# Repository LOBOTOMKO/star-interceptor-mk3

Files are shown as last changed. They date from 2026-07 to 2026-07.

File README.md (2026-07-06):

# Star Interceptor MK III

**An autonomous celestial-tracking telescope mount — designed and built end to end: mechanism, technical drawings, custom PCB, firmware, and control app.**

A low-cost, portable two-axis mount that works out where a celestial object sits in the sky from your time and location, then drives itself to follow it across the sky — on its own, for up to 24 hours.

*Regional winner and national finalist, Festival of Science & Technology (AMAVET).*

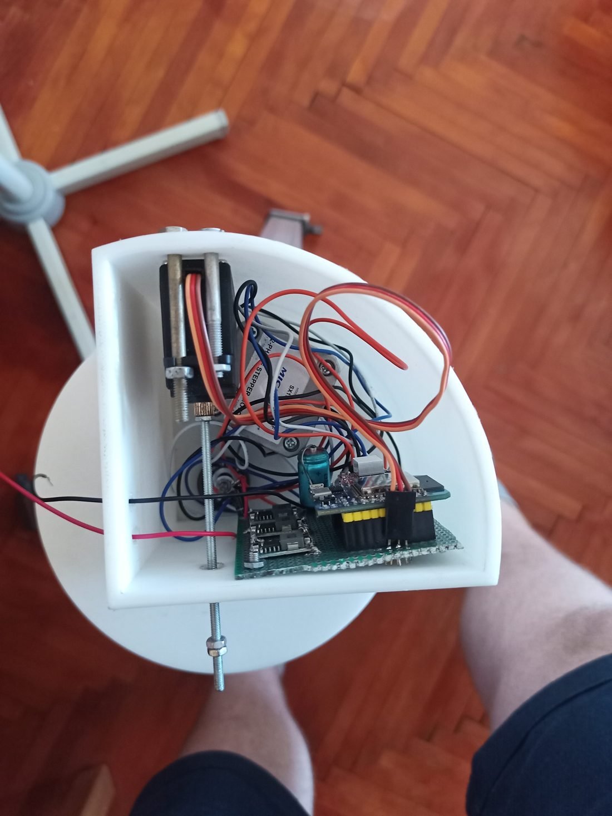
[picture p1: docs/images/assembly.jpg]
The assembled instrument — steppers, custom board and wiring inside the 3D-printed base


---

## Overview

I built this because the cheap telescope I had as a kid sat on a tripod too flimsy to hold the full Moon steady in view — and the computer-controlled mount I'd been promised never got built. So I spent about a year researching the technologies it would need and built it myself.

The goal was a genuinely affordable, durable, portable platform that points a telescope precisely from a smartphone — and, just as much, a project to push my own engineering across every layer: mechanical design, electronics, firmware, and software.

The result is a working instrument that ran in front of a competition jury twice, in two countries.

---

## How it works

The system answers one question, continuously: **where is this object right now?** From the observer's coordinates, elevation and the current time, it computes the target's apparent position, converts that into a pair of axis angles — azimuth and altitude — and drives the mount to match, recomputing as the sky moves.

```
observer location + time + target  →  celestial-position computation  →  azimuth / altitude  →  two-axis motion
```

---

## The build — three generations, each solving the last one's failure

The mount wasn't designed once and finished. It evolved through **diagnosed failures** — each version fixed a specific, observed problem in the one before. That loop of build → test → find the real fault → redesign is the core of the project.

**Generation 1 — dual stepper, H-bridge drive.**
Both axes driven by stepper motors through H-bridges. Original firmware preserved in [`firmware/history/gen1-dual-stepper/`](firmware/history/gen1-dual-stepper/).
*The failure:* with the drivers powered down, the telescope's own weight back-drove the motors and it slipped off target — along with vibration, jitter and audible noise.

**Generation 2 — servo elevation (MG996R).**
Moving elevation to a metal-geared servo with position feedback fixed the back-driving.
*The new failure:* the servo's acceleration couldn't be controlled, so under the inertia of the optics it fell into a chaotic state and couldn't reliably settle on the commanded angle.

**Generation 3 — stepper + worm gear (in development).**
The current direction: a worm-gear-driven stepper for elevation. A worm drive can't be back-driven, raises load capacity, and removes the jerk on pointing changes. This is the MK III.

---

## Software

Celestial positions are computed in **Python**, using the `ephem` library — chosen because it handles far more bodies than the alternatives. The control app is built in **Kotlin** with an XML interface in **Android Studio** (both taught myself for this project), bridged to the Python calculation through **Chaquopy**. The mount runs a **Bluetooth Low Energy** server on the **ESP32**.

The step I'm most proud of is how tracking is handled. In the first version the phone recomputed the target every 10 seconds and pushed the mount a correction. In the second, the phone hands the mount a compact array of upcoming orientations, and the mount then tracks the object **entirely on its own — no phone connection needed — for up to 24 hours.**

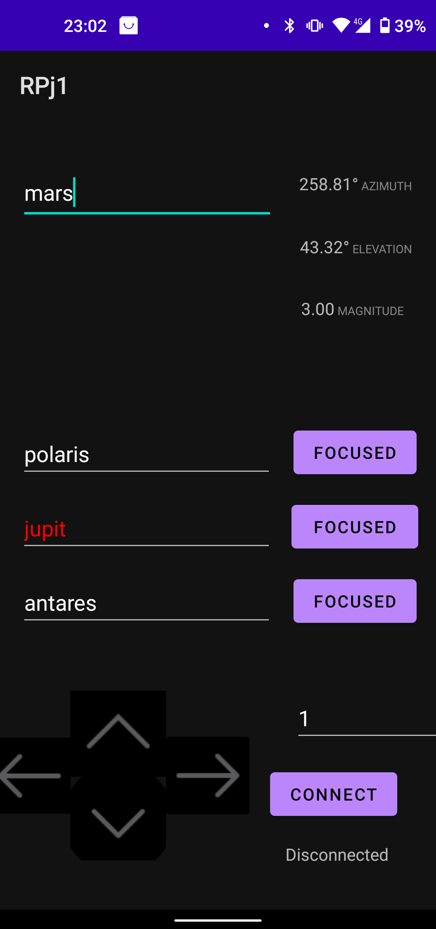
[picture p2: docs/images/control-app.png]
The control app — target entry with live azimuth, elevation and magnitude readout, plus manual controls


---

## Engineering detail: S-curve acceleration

Driven naively, stepper motors start and stop abruptly — which shows up as vibration, noise, and missed steps that cost pointing accuracy. To fix it I derived a **sigmoid-based S-curve acceleration profile**: rather than jumping between step speeds, the firmware ramps the delay between steps smoothly up to speed and back down again, so each axis accelerates and brakes gently. The result is quiet, controlled motion that doesn't shake the optics or lose position.

```cpp
double computeY(double x, double k, double d, double v) {
    double t1 = 1.0 / (1.0 + exp(-k * (x - (2*log(v)/k) + d)));
    double t2 = 1.0 / (1.0 + exp(-k * (x + (2*log(v)/k) - d)));
    return 0 - fabs(t1 - t2) * v;   // per-step delay along the acceleration curve
}
```

---

## Electronics & power

The electronics began as stepper drivers wired by hand and became a consolidated unit. I moved from **A4988 to DRV8825** drivers for finer microstepping, lower noise and a cleaner control interface, then brought the ESP32, the drivers and a Mini-360 buck converter together onto a **custom PCB designed in KiCad** — a plug-and-play board rather than a breadboard of modules. An SMD revision of the board is already designed.

Power comes from an **18650 pack** I reconfigured from a series/parallel layout into full series, to supply the 8 V+ the DRV8825 drivers need to run.

**Schematic (KiCad)**
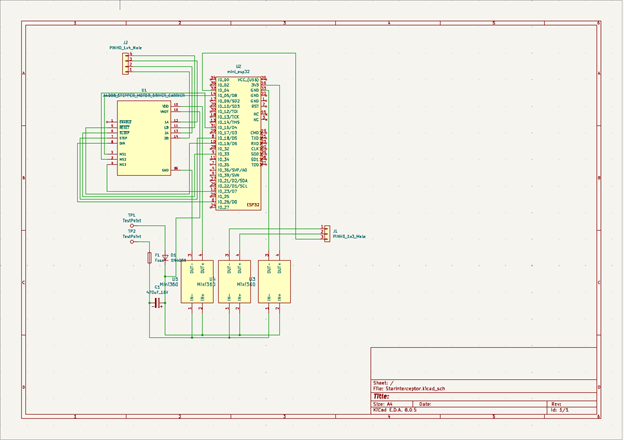
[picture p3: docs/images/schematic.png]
Custom PCB schematic — ESP32, stepper driver, buck converters and protection on one board


**Board layout (KiCad)**
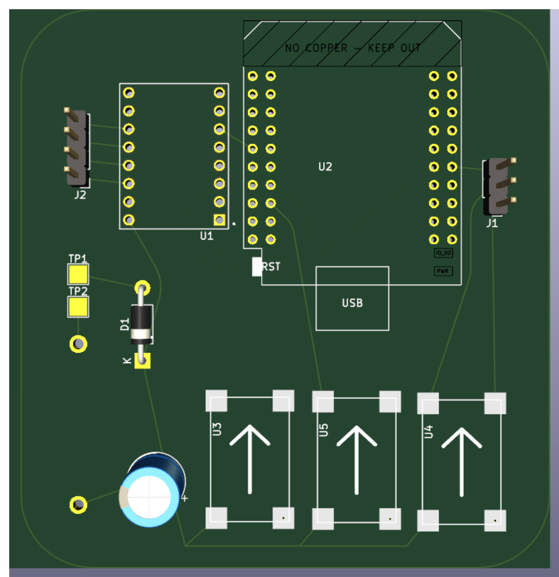
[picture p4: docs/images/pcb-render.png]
PCB layout render


**Power**
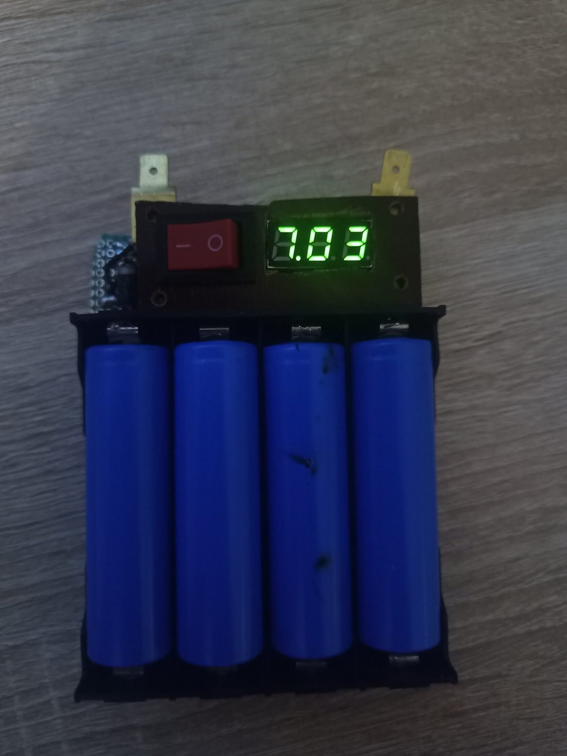
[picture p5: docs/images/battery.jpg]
The 18650 battery pack, reconfigured to full series for driver headroom


> Note: the original KiCad source files were lost; the schematic and board images above are the surviving record of the electronics design.

---

## CAD & technical documentation

The full mechanism was modelled in **Autodesk Fusion 360** and exported through PrusaSlicer for 3D printing. Beyond the models, every part is captured as a **dimensioned technical drawing** — dome and base included — with tolerances, radii, section views and title blocks. This is production documentation, not just a 3D file: drawings another person could manufacture from directly.

| Dome (Kupola) | Base (Základňa) |
|:---:|:---:|
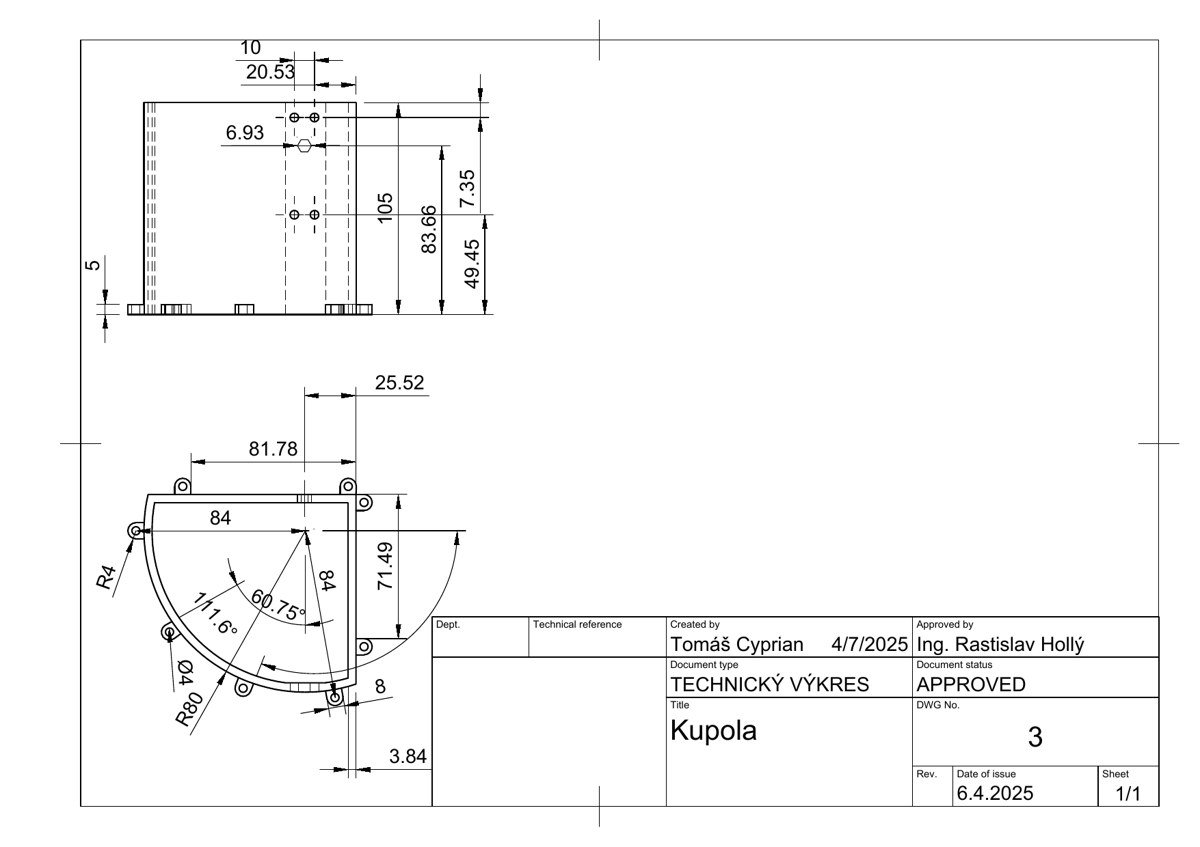
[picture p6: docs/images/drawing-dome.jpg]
Technical drawing of the dome, fully dimensioned
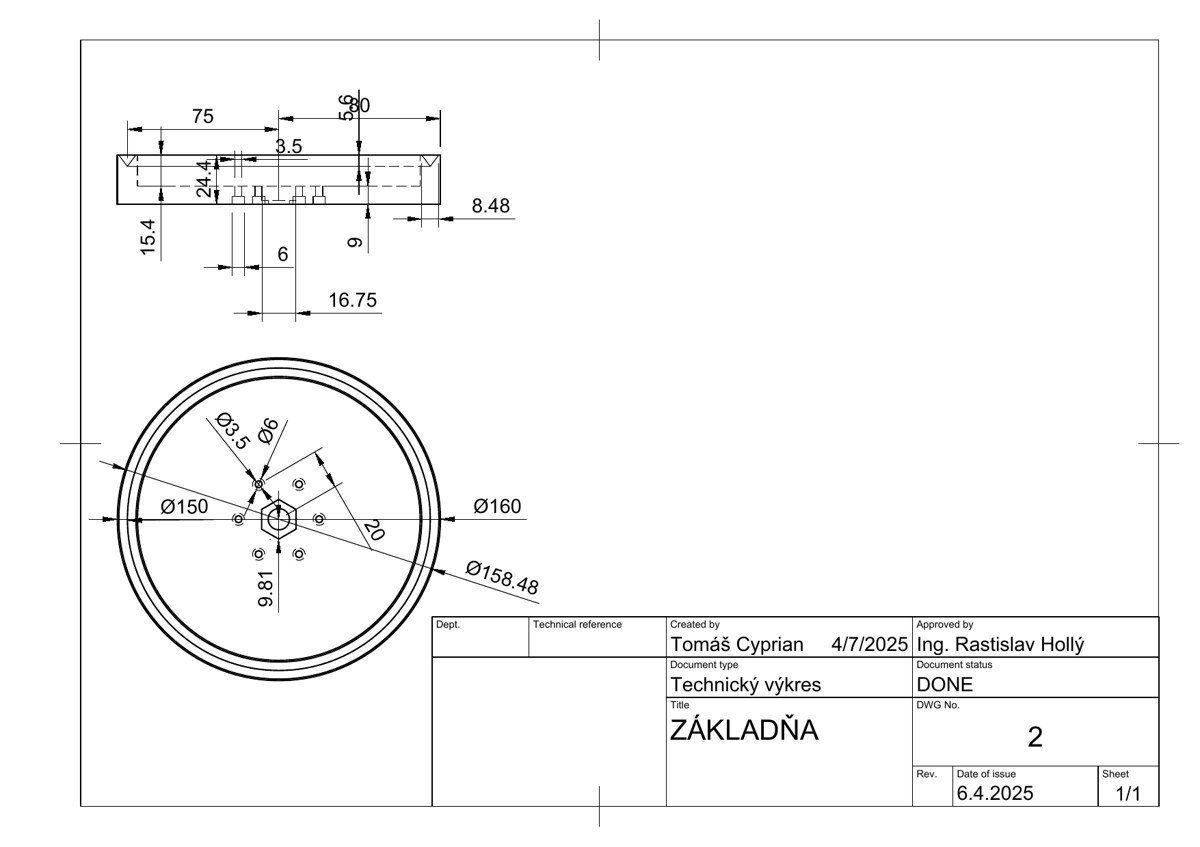
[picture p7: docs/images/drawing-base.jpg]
Technical drawing of the base with title block
|  |  |

**3D models** — click through for GitHub's interactive rotate/zoom viewer:
[Základňa (base)](cad/stl/Zakladna-v2.stl) · [Točňa (turntable)](cad/stl/Tocna-v2.stl) · [Námer 1](cad/stl/Namer1-v2.stl) · [Námer 2](cad/stl/Namer2-v2.stl)

> More early-stage STL variants and other archived files live in the earlier [Star-Interceptor](https://github.com/LOBOTOMKO/Star-Interceptor) repository (`3D/`).

---

## Cost

The affordability goal wasn't a slogan — the complete bill of materials came to **€31.85**. Designing to a real cost target, and hitting it, was part of the engineering brief I set myself.

| Component | Cost |
|---|---|
| ESP32 (Wemos D1 mini) | €9.90 |
| Stepper motor (17HS4023) | ~€2.50 |
| DRV8825 driver | €2.95 |
| Servo (MG996R) | €6.90 |
| 2× Mini-360 buck converter | €0.95 |
| Battery | €7.70 |
| **Total** | **€31.85** |

---

## Recognition

- **Festival of Science & Technology (AMAVET), 2023** — regional winner (Trenčín region), presented in the national final at INCHEBA Bratislava. Category: Physics & Astronomy.
- **Festival of Science & Technology, 2025** — regional round, Pardubice (Czech Republic). Partners included Foxconn and the University of Pardubice.

---

## Repository structure

```
star-interceptor/
├── firmware/     ESP32 firmware (C/C++) — coordinate transform, motor control, BLE server
├── app/          Android control app (Kotlin / XML)
├── calc/         Python celestial-position calculation (ephem)
├── hardware/     KiCad schematic + PCB layout (images)
├── cad/          Fusion 360 exports + dimensioned technical drawings (PDF)
└── docs/images/  Photos, schematic, board render, drawings, app screenshot
```

---

## About

Designed and built by **Tomáš Cyprian** — Applied Informatics (Robotics & Control Systems).
Open to engineering and design work.

📧 tomas.cyprian.sk@gmail.com

*The project is open for hobbyists and enthusiasts to build on.*

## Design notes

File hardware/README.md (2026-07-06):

# hardware/

Electronics design — custom PCB carrying the ESP32, stepper driver, buck converters and protection.

Designed in KiCad. **Note:** the original KiCad source files were lost; the schematic and board-layout images in `docs/images/` (`schematic.png`, `pcb-render.png`) are the surviving record. If the `.kicad_pro` / `.kicad_sch` / `.kicad_pcb` files are recovered, add them here.

**Add here:** any recovered KiCad project files and exported gerbers.

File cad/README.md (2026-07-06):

# cad/

Mechanical design — modelled in Autodesk Fusion 360, printed via PrusaSlicer.

Includes dimensioned technical drawings (dome and base) with tolerances, section views and title blocks.

**STL meshes:** `stl/` holds the current printable meshes — open one on GitHub to get its interactive rotate/zoom viewer. More early-stage variants and other archived files live in the earlier [Star-Interceptor](https://github.com/LOBOTOMKO/Star-Interceptor) repository (`3D/`).

**Add here:** Fusion exports (`.f3d` / `.step`) and the technical-drawing PDFs.

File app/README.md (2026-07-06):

# app/

Android control application (Kotlin, XML UI, built in Android Studio).

- target selection and manual control
- computes celestial positions via the bundled Python (`calc/`) through Chaquopy
- sends orientations to the mount over Bluetooth Low Energy

**Add here:** the Android Studio project (module sources, `build.gradle`, resources). Build artifacts are ignored by `.gitignore`.

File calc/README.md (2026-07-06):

# calc/

Celestial-position calculation (Python, `ephem`).

Given an observer's latitude, longitude, elevation and the current time, computes a target body's azimuth, altitude and magnitude — and produces the sequence of upcoming orientations used for autonomous tracking.

**Add here:** the Python source and a `requirements.txt` (e.g. `ephem`).

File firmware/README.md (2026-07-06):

# firmware/

ESP32 firmware (C/C++).

Handles the real-time work on the mount:
- receives target orientations over Bluetooth Low Energy
- runs the coordinate → axis-angle logic
- drives the stepper motor(s) with the S-curve acceleration profile
- (v2) tracks an object autonomously from a buffered orientation array

**Add here:** the ESP32 source (`.ino` / `.cpp` / `.h`) and any PlatformIO/Arduino project files.

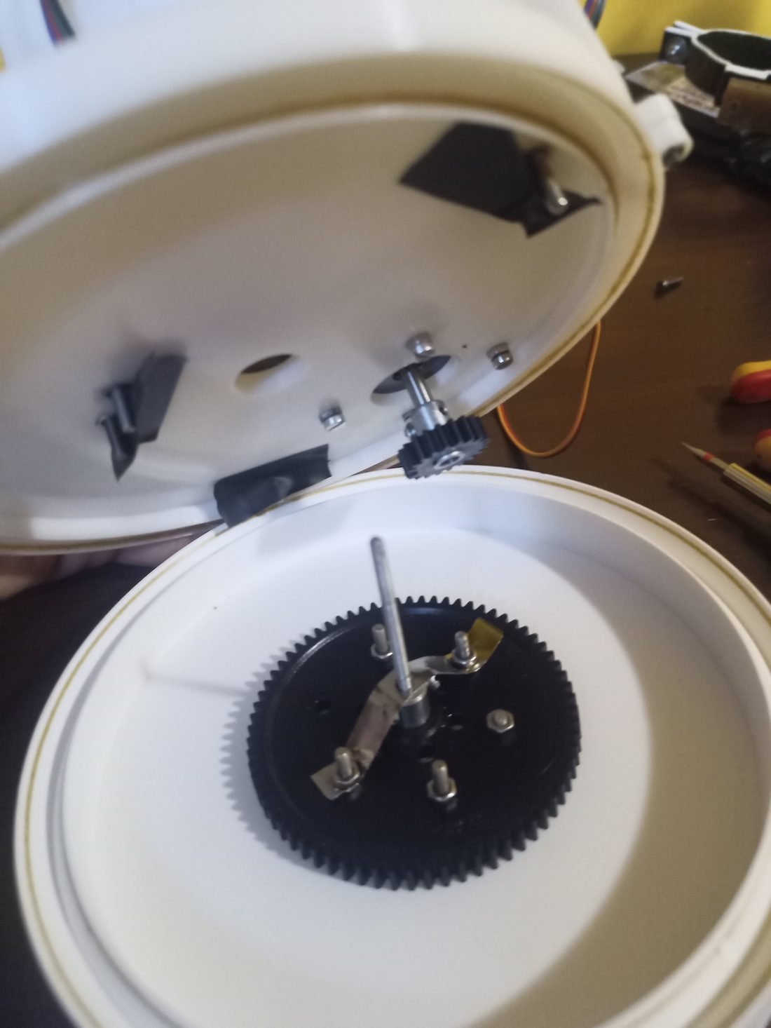
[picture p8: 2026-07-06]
docs/images/drivetrain.jpg

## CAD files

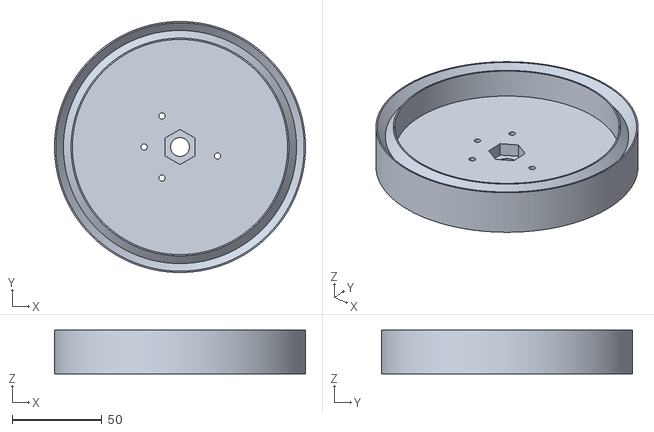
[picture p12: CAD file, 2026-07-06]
cad/stl/Zakladna-v2.stl
140.0 x 140.0 x 24.4

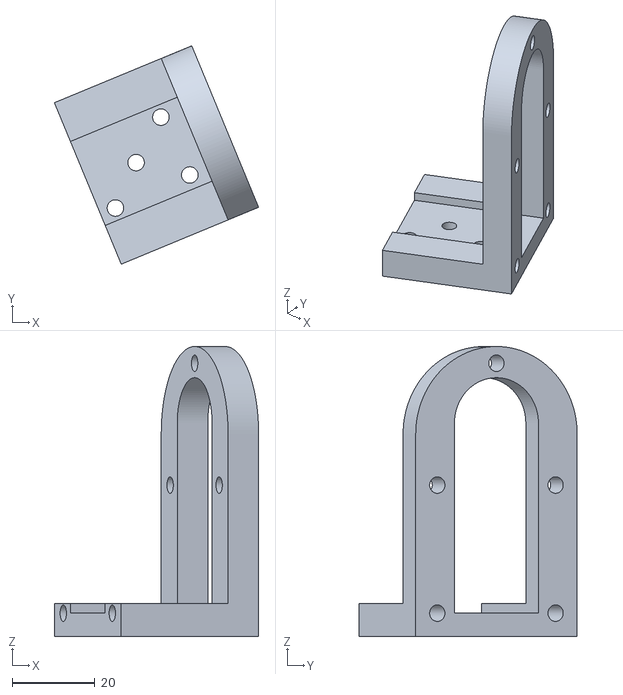
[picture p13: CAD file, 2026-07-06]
cad/stl/Namer1-v2.stl
49.4 x 52.9 x 70.2

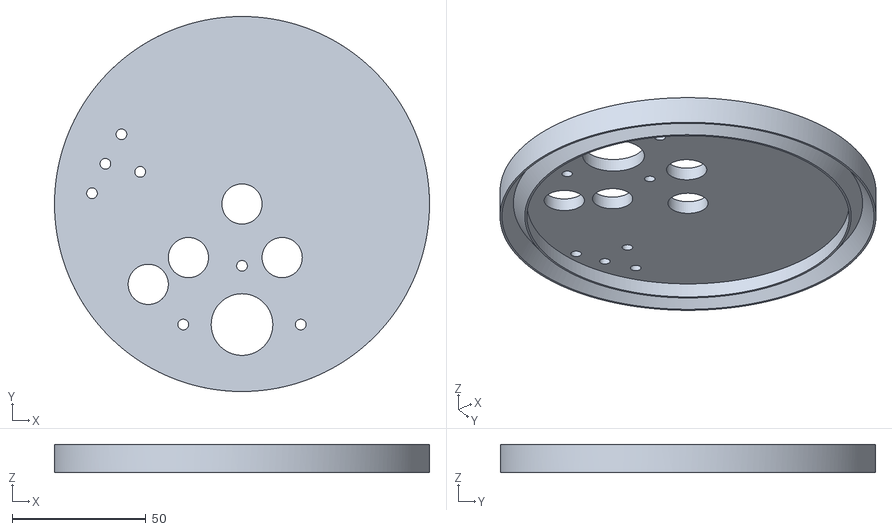
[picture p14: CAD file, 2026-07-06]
cad/stl/Tocna-v2.stl
140.0 x 140.0 x 10.6

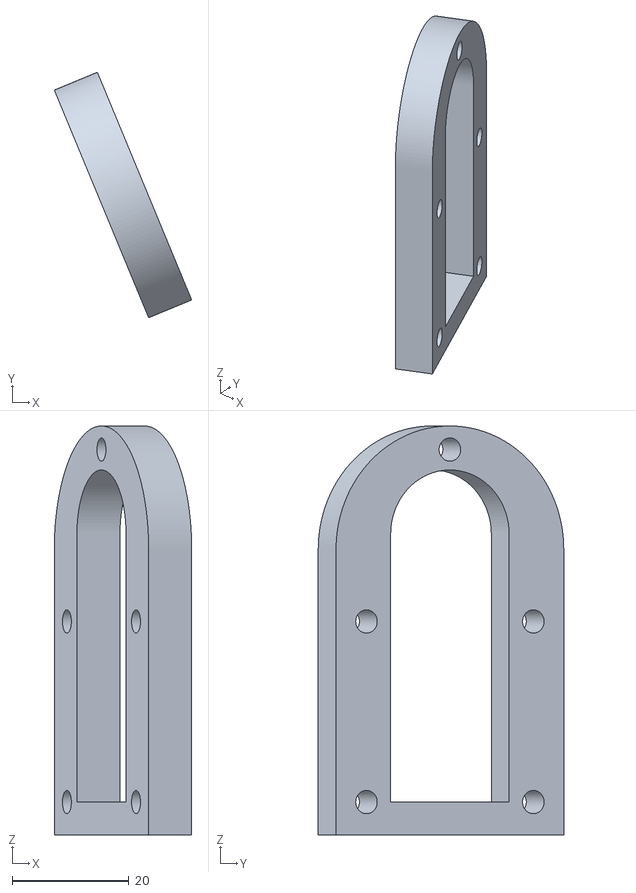
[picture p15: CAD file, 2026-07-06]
cad/stl/Namer2-v2.stl
23.6 x 42.1 x 70.2

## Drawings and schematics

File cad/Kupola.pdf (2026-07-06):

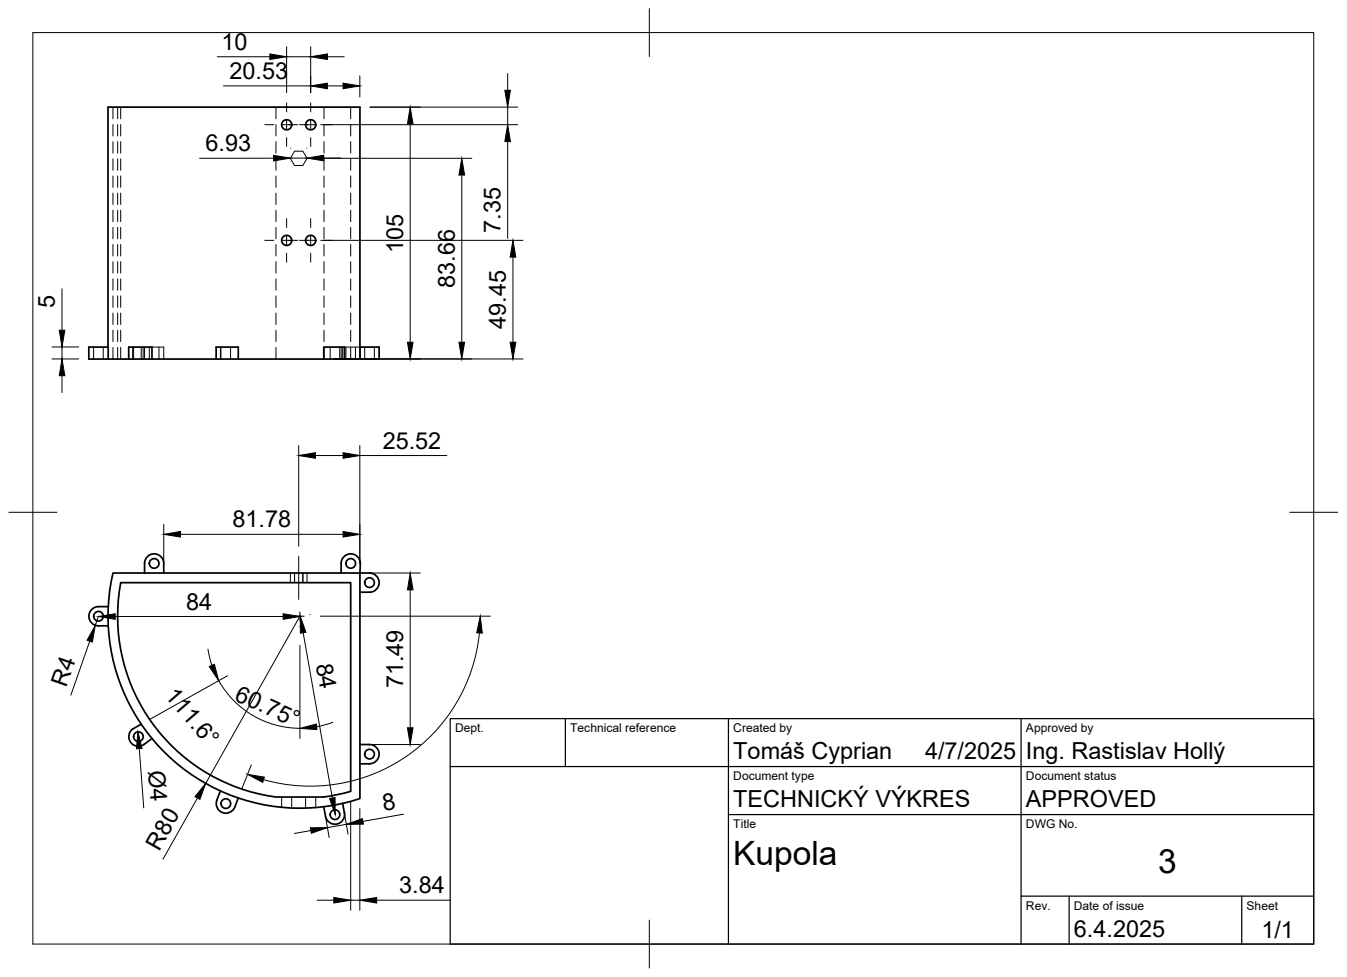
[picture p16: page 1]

Dept. | Technical reference | Created by Tomáš Cyprian 4/7/2025 | Approved by Ing. Rastislav Hollý

Document type TECHNICKÝ VÝKRES | Document status APPROVED

Title Kupola | DWG No. 3

Rev. | Date of issue 6.4.2025 | Sheet 1/1

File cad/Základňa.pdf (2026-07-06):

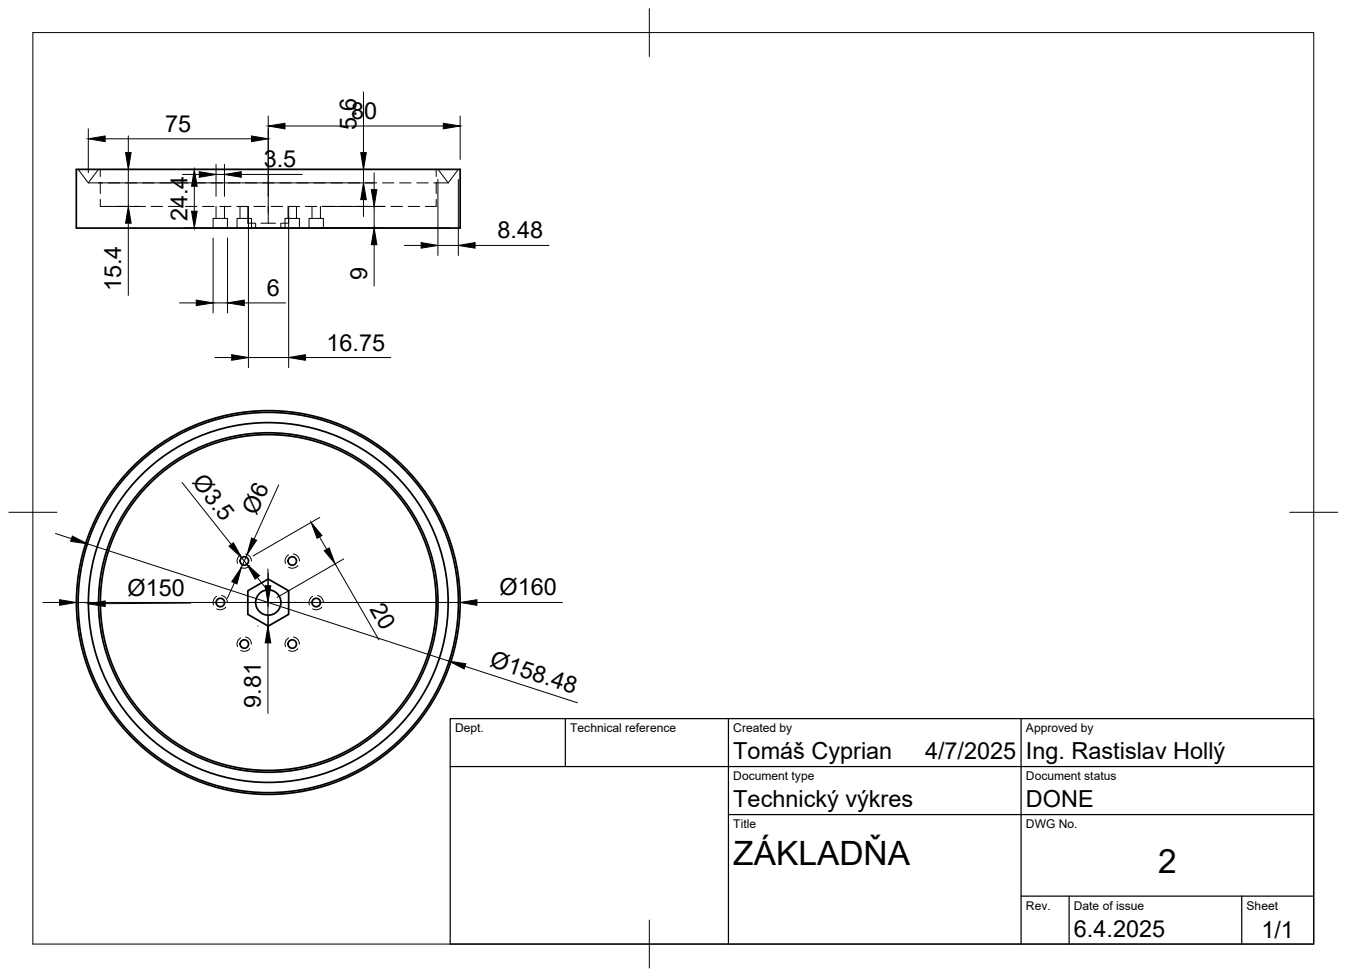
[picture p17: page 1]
Tomáš Cyprian; Ing. Rastislav Hollý 24.4

Dept. | Technical reference | Created by 4/7/2025 | Approved by

Document type Technický výkres | Document status DONE

Title ZÁKLADŇA | DWG No. 2

Rev. | Date of issue 6.4.2025 | Sheet 1/1

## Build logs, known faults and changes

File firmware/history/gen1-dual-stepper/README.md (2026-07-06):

# firmware/history/gen1-dual-stepper/

The original Generation 1 firmware, kept here as a record of the project's evolution (see the main [README](../../../README.md#the-build--three-generations-each-solving-the-last-ones-failure)).

In this generation **both axes — azimuth and elevation — were driven by stepper motors**, each stepped directly through a 4-pin H-bridge sequence (no microstepping driver yet). Target coordinates arrived over Bluetooth Low Energy (`main.ino`) and were converted into step counts for MOTOR1 (azimuth) and MOTOR2 (elevation).

- `main.ino` — the BLE-driven dual-stepper controller: receives a `latitude longitude` pair, converts it into step counts, and drives both H-bridge steppers.
- `rxtx1.ino` — an earlier bring-up sketch exercising the elevation and azimuth H-bridge pin sequences directly, before the BLE layer was added.

**Why it was replaced:** with the H-bridge drivers powered down between moves, the telescope's own weight back-drove the elevation motor and it slipped off target, along with vibration, jitter and audible noise during stepping. Generation 2 moved elevation to a metal-geared servo (MG996R) with position feedback to fix the back-driving; Generation 3 (the current firmware in `firmware/`) returns elevation to a stepper, but now through a worm gear, which can't be back-driven.

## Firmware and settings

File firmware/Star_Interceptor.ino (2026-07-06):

/*
███████╗████████╗ █████╗ ██████╗     ██╗███╗   ██╗████████╗███████╗██████╗  ██████╗███████╗██████╗ ████████╗ ██████╗ ██████╗ 
██╔════╝╚══██╔══╝██╔══██╗██╔══██╗    ██║████╗  ██║╚══██╔══╝██╔════╝██╔══██╗██╔════╝██╔════╝██╔══██╗╚══██╔══╝██╔═══██╗██╔══██╗
███████╗   ██║   ███████║██████╔╝    ██║██╔██╗ ██║   ██║   █████╗  ██████╔╝██║     █████╗  ██████╔╝   ██║   ██║   ██║██████╔╝
╚════██║   ██║   ██╔══██║██╔══██╗    ██║██║╚██╗██║   ██║   ██╔══╝  ██╔══██╗██║     ██╔══╝  ██╔═══╝    ██║   ██║   ██║██╔══██╗
███████║   ██║   ██║  ██║██║  ██║    ██║██║ ╚████║   ██║   ███████╗██║  ██║╚██████╗███████╗██║        ██║   ╚██████╔╝██║  ██║
╚══════╝   ╚═╝   ╚═╝  ╚═╝╚═╝  ╚═╝    ╚═╝╚═╝  ╚═══╝   ╚═╝   ╚══════╝╚═╝  ╚═╝ ╚═════╝╚══════╝╚═╝        ╚═╝    ╚═════╝ ╚═╝  ╚═╝                                                                                                                           
*/





//MS1 repin
#include <BLEDevice.h>
#define SERVICE_UUID        "6e400001-b5a3-f393-e0a9-e50e24dcca9e"
#define CHARACTERISTIC_UUID "6e400003-b5a3-f393-e0a9-e50e24dcca9e"

#include <thread>
#include <future>
#include <atomic>
#include <ESP32Servo.h>
#define SERVO_PIN 4
Servo servoMotor;

#include <FastAccelStepper.h>
FastAccelStepperEngine engine = FastAccelStepperEngine();
FastAccelStepper *stepper = NULL;



int led = 2;

// = 0,5n
float stepAngle = 0.016071428571875;//0.5142857143;
int   speed     =     1;

float azimuth   = 0.0;
float elevation = 90.0;

//Stepper
int dir       = 26;
int step      = 18;
int sleepPin  = 33;
int reset     = 19;
int enablePin = 22;

int MS1       = 14;
int MS2       = 16;
int MS3       = 23;

static int n = 2; 
static float* floatArray;  

float azimuthal = 30.0;
float elevational  = 31.0;

float planet = 34.0;


/*
  _____                    __  .__                      
_/ ____\_ __  ____   _____/  |_|__| ____   ____   ______
\   __\  |  \/    \_/ ___\   __\  |/  _ \ /    \ /  ___/
 |  | |  |  /   |  \  \___|  | |  (  <_> )   |  \\___ \ 
 |__| |____/|___|  /\___  >__| |__|\____/|___|  /____  >
                 \/     \/                    \/     \/
*/
std::atomic<bool> keepRunning(true);

float calculateClosestApproach(float start_angle, float target_angle, float step_size) {
    float raw_diff = target_angle - start_angle;
    
    if (raw_diff > 180.0) {
        raw_diff -= 360.0;
    } else if (raw_diff < -180.0) {
        raw_diff += 360.0;
    }
    
    float nearest_step = round(raw_diff / step_size) * step_size;
    
    return nearest_step;
}

float* stringToFloatArray(const std::string& value) {
    if (value.empty()) {
        return nullptr;
    }

    const uint8_t* data = reinterpret_cast<const uint8_t*>(value.c_str());
    size_t dataSize = value.length();
    
    size_t numFloats = dataSize / sizeof(float);
    
    if (numFloats == 0) {
        return nullptr;
    }


    float* floatArray = new float[numFloats];
    memcpy(floatArray, data, numFloats * sizeof(float));
  
    for(size_t i = 0; i < numFloats; i++) {
        Serial.println(floatArray[i]);
    }
    
    return floatArray;
}

void turn(float angle, bool elevate){

  Serial.println("Turn Signal ====================================================");
  //Serial.println("angle: " + String(angle,4));
  //Serial.println("elevate: " + String(elevate,4));
  if (elevate)
  {
    if (angle > 90 && angle < 150){
      servoMotor.write(angle);
      elevation = angle;
      Serial.println("Elevation: " + String(elevation, 3));
    }
  } 
  else
  { 
    float clossestAngle = calculateClosestApproach(azimuth, angle, stepAngle);
    int steps = int(clossestAngle/stepAngle);
    azimuth = azimuth + clossestAngle;
    Serial.println("steps: " + String(steps) + "| angle: " + String(azimuth, 6) + "Azimuth");

    //digitalWrite(enablePin, LOW);
    stepper->move(steps);
    while(stepper->isRunning()) {
      yield();
    }

    //digitalWrite(enablePin, HIGH);

    digitalWrite(dir, LOW);
    digitalWrite(led, LOW);
  }
}

void trackObject(float* Angles, int speed) {
    auto nextTimePoint = std::chrono::steady_clock::now();
    int index = 1;
    while (keepRunning) {
        nextTimePoint += std::chrono::seconds(speed); 
        //subFunction(Angles[index], Angles[index+1]);
        Serial.println("Azimuth" + String(Angles[index + 1]));
        turn(Angles[index + 1], false);  // Elevation
        Serial.println("Elevation" + String(Angles[index]));
        turn(Angles[index], true);  
        
        index += 2;
        std::future<void> result = std::async(std::launch::async, [nextTimePoint]() {
            std::this_thread::sleep_until(nextTimePoint); 
        });
        result.get(); 
    }
}

/*
 _______   ___       _______  
|   _  "\ |"  |     /"     "| 
(. |_)  :)||  |    (: ______) 
|:     \/ |:  |     \/    |   
(|  _  \\  \  |___  // ___)_  
|: |_)  :)( \_|:  \(:      "| 
(_______/  \_______)\_______) 
                              
*/
BLECharacteristic* pCharacteristic;

void handleAsyncTask(float* Data, int speed) {
    auto asyncFuture = std::async(std::launch::async, trackObject, Data, speed); // Start the asynchronous function
}
class MyCallbacks : public BLECharacteristicCallbacks {
public:
    int speed = 10;
    float* Data;

    void onWrite(BLECharacteristic* characteristic) override {
        keepRunning = false;
        String arduinoString = pCharacteristic->getValue();
        std::string value(arduinoString.begin(), arduinoString.end());

        Data = stringToFloatArray(value);

        switch (static_cast<int>(Data[0])) {
    case 30:
        turn(azimuth + Data[1], false);
        Serial.println("Azimuth: HERE!!!!");
        break;
    case 31:{
        float finalElevation = elevation + Data[1];
        if (finalElevation < 170 && finalElevation > 90) {
            servoMotor.write(finalElevation);
            elevation = finalElevation;
            Serial.println("elevation: " + String(elevation, 6));
        }
        else {
            Serial.println("Elevation out of bounds!!!");
        }
        break;
    }
    case 32:{
      azimuth = Data[1];
      elevation = Data[2];
    }
    default: {
        if (Data[0] != planet) {
            planet = Data[0];
            keepRunning = true;

            if (Data != nullptr) {
                std::thread taskThread(handleAsyncTask, Data, speed);
                taskThread.detach(); 
            } else {
                Serial.println("Failed to parse data.");
            }
        }
    }   
    break;
}

    }
};

class MyServerCallbacks : public BLEServerCallbacks {
    void onConnect(BLEServer* pServer) override {
        Serial.println("Device connected");
    }

    void onDisconnect(BLEServer* pServer) override {
        Serial.println("Device disconnected");
        pServer->startAdvertising();
    }
};

/*
               __                
  ______ _____/  |_ __ ________  
 /  ___// __ \   __\  |  \____ \ 
 \___ \\  ___/|  | |  |  /  |_> >
/____  >\___  >__| |____/|   __/ 
     \/     \/           |__|   
*/

void setup() {
    Serial.begin(115200);
    floatArray = (float*)malloc(n * sizeof(float));
    if (floatArray == NULL) {
        Serial.println("Memory allocation failed!");
        return;
    }

    BLEDevice::init("noscope");
    BLEServer* pServer = BLEDevice::createServer();
    pServer->setCallbacks(new MyServerCallbacks());

    BLEService* pService = pServer->createService(SERVICE_UUID);
    pCharacteristic = pService->createCharacteristic(
        CHARACTERISTIC_UUID,
        BLECharacteristic::PROPERTY_WRITE
    );

    pCharacteristic->setCallbacks(new MyCallbacks());
    pService->start();
    BLEAdvertising* pAdvertising = pServer->getAdvertising();
    pAdvertising->addServiceUUID(SERVICE_UUID);
    pAdvertising->start();

    Serial.println("Characteristic defined! Now you can write data to it.");

    pinMode(led, OUTPUT);

    //Stepper
    pinMode(dir, OUTPUT);
    pinMode(step, OUTPUT);
    pinMode(sleepPin,OUTPUT);
    pinMode(reset, OUTPUT);
    pinMode(enablePin, OUTPUT);

    pinMode(MS1, OUTPUT);
    pinMode(MS2, OUTPUT);
    pinMode(MS3, OUTPUT);
    digitalWrite(MS1, HIGH);
    digitalWrite(MS2, HIGH);
    digitalWrite(MS3, HIGH);
    digitalWrite(sleepPin, HIGH);
    digitalWrite(reset, HIGH);


    engine.init();
    stepper = engine.stepperConnectToPin(step);
    stepper->setDirectionPin(dir);
    stepper->setSpeedInHz(5000);     
    stepper->setAcceleration(800);     
    stepper->enableOutputs();

  
    servoMotor.attach(SERVO_PIN);
    servoMotor.write(90);

}

void loop() {
}

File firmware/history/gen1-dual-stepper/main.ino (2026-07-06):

#include <BLEDevice.h>
#include <BLEServer.h>
#include <BLEUtils.h>

#include <string>



int pins1[] = {25,32,26,33};
int pins2[] = {27,13,14,12};

int step1 = 0;
int step2 = 0;

// = 0,7488
float angle = 0.7488;
int   speed = 5;
int   hold  = 2;

float latitude     = 0.000;
float longtitude   = 0.000;




#define SERVICE_UUID        "6e400001-b5a3-f393-e0a9-e50e24dcca9e"
#define CHARACTERISTIC_UUID "6e400003-b5a3-f393-e0a9-e50e24dcca9e"

void turn(int steps, bool motor){
  if (steps != 0){
  Serial.print(steps);
  if (motor){

    Serial.print(steps + "_MOTOR1");
    if (steps > 0){ 

      Serial.println("_MOTOR1:clockwise");
      for (int i = 0; i <= steps;i++){      
          step1++;
          if (step1 == 4){
            step1 = 0;
          }

          digitalWrite(pins1[step1], HIGH);
          delay(hold);
          digitalWrite(pins1[step1], LOW);
          delay(speed);
        }
    }


    else{
      
      Serial.println("MOTOR1:counterclockwise");
      for (int i = steps; i <= 0;i++){     
          step1--;
          if (step1 == -1){
            step1 = 3;
          }

          digitalWrite(pins1[step1], HIGH);
          delay(hold);
          digitalWrite(pins1[step1], LOW);
          delay(speed);
        }
    }
  }
  else{
      Serial.println(steps+ "_MOTOR2:STEPS");
        if (steps > 0){
      Serial.println("MOTOR2:clockwise");
      for (int i = 0; i <= steps;i++){     
          step1++;
          if (step1 == 4){
            step1 = 0;
          }

          digitalWrite(pins2[step1], HIGH);

          delay(hold);
          digitalWrite(pins2[step1], LOW);

          delay(speed);
        }
    }


    else{
      Serial.println("MOTOR2:counterclockwise");
      for (int i = steps; i <= 0;i++){     
          step1--;
          if (step1 == -1){
            step1 = 3;
          }

          digitalWrite(pins2[step1], HIGH);
          delay(hold);
          digitalWrite(pins2[step1], LOW);
          delay(speed);
        }
    }
  }
  }
}

BLECharacteristic *pCharacteristic;

class MyCallbacks : public BLECharacteristicCallbacks {
void onWrite(BLECharacteristic* characteristic) {
  std::__cxx11::basic_string<char> value = characteristic->getValue();

  int   index       = value.find(" ");
        latitude    += std::stof(value.substr(0,index)) ;
        longtitude  += std::stof(value.substr(index)  ) ;

  Serial.println(value.c_str());
  Serial.println(latitude,   3);
  Serial.println(longtitude, 3);

  turn(round(longtitude/angle),1);
  longtitude = longtitude/angle - round(longtitude/angle);
  Serial.print(longtitude, 3);
  Serial.println(":reaminer, MOTOR1");


  turn(round(latitude/angle),0);
  latitude = latitude/angle - round(latitude/angle);
  Serial.print  (latitude,3   );
  Serial.println(":reaminer, MOTOR2"   );


  digitalWrite(2, HIGH);
  delay(500);
  digitalWrite(2, LOW);

}

};

class MyServerCallbacks : public BLEServerCallbacks {
  void onConnect(BLEServer* pServer) {
    Serial.println("Device connected");
  }

  void onDisconnect(BLEServer* pServer) {
    Serial.println("Device disconnected");
    pServer->startAdvertising();
  }
};

void setup() {
  Serial.begin(115200);
  while (!Serial) {}

  BLEDevice::init("noscope");
  BLEServer *pServer = BLEDevice::createServer();
  pServer->setCallbacks(new MyServerCallbacks()); // Assign the server callbacks

  BLEService *pService = pServer->createService(SERVICE_UUID);
  pCharacteristic = pService->createCharacteristic(
    CHARACTERISTIC_UUID,
    BLECharacteristic::PROPERTY_WRITE
  );

  pCharacteristic->setCallbacks(new MyCallbacks()); // Assign the characteristic callbacks

  pService->start();

  BLEAdvertising *pAdvertising = pServer->getAdvertising();
  pAdvertising->addServiceUUID(SERVICE_UUID);
  pAdvertising->start();

  Serial.println("Characteristic defined! Now you can write data to it.");


  pinMode(2, OUTPUT);
  for (int i = 0; i <5 ; i++){
    pinMode(pins1[i],OUTPUT);
    pinMode(pins2[i],OUTPUT);

  }
}

void loop() {

}

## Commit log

2026-07-06 Initial commit: Star Interceptor MK III
    Autonomous celestial-tracking telescope mount — ESP32 firmware,
    Android control app (Kotlin + Chaquopy), Python celestial-position
    calculation, KiCad electronics record, and Fusion 360 / dimensioned
    technical drawings.
2026-07-06 Add Generation 1 firmware history and STL reference
    Preserve the original dual-stepper/H-bridge firmware (elevation was
    also stepper-driven before the MG996R servo, then the Gen 3 worm-gear
    stepper) under firmware/history/. Point CAD readers to the STL meshes
    kept in the earlier Star-Interceptor repo instead of duplicating them.
2026-07-06 Add STL meshes with links to GitHub's native 3D viewer
    Copy the current-generation printable STL parts (base, turntable,
    brackets) from the archived Star-Interceptor repo into cad/stl/, and
    link them from the README so readers can open GitHub's built-in
    interactive rotate/zoom viewer for each part.
    [Namer1-v2.stl, Namer2-v2.stl, Tocna-v2.stl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]
